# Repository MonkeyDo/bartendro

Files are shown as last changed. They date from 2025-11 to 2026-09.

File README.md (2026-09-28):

Original README 
============

Programs for the various systems of the Bartendro drink dispensing robot.

Created by [Pierre Michael](https://github.com/pmich) and [Robert Kaye](https://github.com/mayhem) ~ Copyright (c) Party Robotics 2010-2013

All of the source code in this repository is licensed under the GNU Public License 2.0.
The hardware schematic and layouts are licensed using the Creative Commons 
Attribution-ShareAlike 3.0 Unported license.

The source tree is laid out as follows:
  * firmware - source code (C) for the dispenser and router boards
  * scripts  - scripts to make running the bartendro software easier
  * ui       - web interface for the bot, written in python.

Fork README 
============

Requirements
==================================
Bartendro requires not just a RPI 4 but many other parts: a custom router board printed by Party Robotics, peristaltic pump dispensers, their individual mini-router boards, cabling, tubing, etc - the open schematics for these can be found in the [original repository in the /hardware folder.](https://github.com/partyrobotics/bartendro)

This project requires that you build your own Bartendro or procure one from a former Kickstart backer or client.

Without it the code will only run in Debug mode.

Code has been tested as working on
==================================
* [x] Raspberry Pi Os (Legacy, 32-bit) / Buster-armhf-lite (June 2019) / Note: only by using SD card image produced in 2021, Buster no longer supported by Raspbian
* [x] Raspberry Pi OS (Legacy, 32-bit) / Bullseye-armhf-lite (Aug 2021)
* [ ] Raspberry Pi OS (Legacy, 32-bit) / Bookworm-armhf-lite (June 2023)
* [ ] Raspberry Pi OS (Legacy, 32-bit) / trixie-armhf-lite (Aug 2025)
* [ ] Test any arm64-lite version of Raspberry Pi OS / `¯\_ (ツ)_/¯  will it run?`
| here is a link to the [official distro image archive for Raspiberry Pi OS](https://downloads.raspberrypi.com/raspios_lite_armhf/images/)

Releases
==================================
- 2021: .img to be flashed onto an SD card (Working on RPI 3 and 4, based on RaspiOS Bullseye 32-bit): [https://github.com/partyrobotics/bartendro/releases/tag/v-2021-05-21](https://github.com/partyrobotics/bartendro/releases/tag/v-2021-05-21)
- 2026: A snapshot of Bartendro as it was running in 2021 with python 2, before we merge in some improvements that were added at a later date. Removes "turbo mode" and "sobriety check" features that we are not going to use.: [https://github.com/MonkeyDo/bartendro/releases/tag/2021-python2](https://github.com/MonkeyDo/bartendro/releases/tag/2021-python2) 
- 2026: 

Getting started
==================================

- Read the [history of Bartendro](https://github.com/MonkeyDo/bartendro/blob/master/docs/history.md)
- Read our [Start Here guide](https://github.com/MonkeyDo/bartendro/blob/master/docs/2026-start-here.md)
- Read the [Install Guide](https://github.com/MonkeyDo/bartendro/blob/master/docs/2026-install-guide.md)
- Read the [User Guide](https://github.com/MonkeyDo/bartendro/blob/master/docs/2026-user-guide.md)
- Get hold of or build your own Bartendro (see Requirements above)
- Flash one of the Releases listed above onto a SD card with at least 4GB of memory and follow the [Install Guide](https://github.com/MonkeyDo/bartendro/blob/master/docs/2026-install-guide.md)
- Once you have the hardware setup and working follow the [User Guide](https://github.com/MonkeyDo/bartendro/blob/master/docs/2026-user-guide.md) to get your Bartendro calibrated and serving robo-cocktails!

Links to relevant code repositories
============

1. Archived bartendro code that can be found in [https://github.com/partyrobotics/bartendro](https://github.com/partyrobotics/bartendro) - what has not been forked from there:
  * hardware - schematics and layouts for the dispenser and router hardware boards
  * tsb - legacy code from our old skool drink bot prototype Tequila Sunrise Bot
2. An open sourced metal frame for holding 3 pumps and all the boards made by Wyolum: [https://github.com/wyolum/bartendro_frame](https://github.com/wyolum/bartendro_frame)
3. Rob's personal repos with additional configuration scripts (outdated): [https://github.com/mayhem/bartendro-config](https://github.com/mayhem/bartendro-config)
4. Rob's collection of BASH scripts to deploy bartendro: [https://github.com/mayhem/bartendro-deploy](https://github.com/mayhem/bartendro-deploy)
5. Ansible Cookbooks from 2013: [https://github.com/mayhem/bartendro-chef-cookbooks](https://github.com/mayhem/bartendro-chef-cookbooks)

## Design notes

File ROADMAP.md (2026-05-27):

# Roadmap

Some improvements we want to make to Bartendro to disentangle it from mayhem's Hippo Oasis and simplify the setup porocess, so it can be used by other people and find a good home.

0. Merge content of /mayhem/bartendro-config into /bartendro/scripts
   * [x] integrate readme.md from there into /docs
   * [x] review the scripts that affect networking - have the RPi setup an AP using available tools on RPI 4
   * [x] review the scripts that point to code running on other machines (this repo /scripts/start_bartendro.sh
   * [ ] create a new install.sh script for newer RaspiOS (Bookworm or above)
   * [ ] modify start_bartendro.sh to use only files within RPI and set to autostart on boot
1. Serve its own wifi access point
   * [ ] Bartendro should not need to connect to internet, so it should create its own AP (Wifi)
   * [ ] install.sh script should automate the selection of raspi-config options necessary for project:
     * [ ] Expand the filesystem (verify this process / requirement)
     * [ ] Set the hostname to bartendro (verify if this is still necessary)
     * [ ] Set the Wifi Country and setup Wifi to a valid network
     * [ ] Advanced: Disable console on serial port, enable serial port
     * [ ] Advanced: Enable I2C
2. Fix annoying bug where drinks will be poured directly from the drinks menu, without waiting for the confirmation screen
   * [x] Bug found to be called 'Turbo Mode' in the code, it exhibits itself when an admin changes settings in the backend and saves, when the backend refreshes it automatically ticks as active this 'turbo mode'
   * [x] Monkey has removed Turbo Mode and Sobriety Test, making a new Release in this repo
3. Better logging within admin UI
   * [ ] write verbose logs to file (rotate logs?)
   * [ ] in admin UI, show logs from file
   * [ ] optional: if admin wishes they can request output of RPI system and kernel logs (makes RPI run `tail -100 /var/log/syslog` or `tail -100 /var/log/kern.log` and displays it in the UI for easy debugging.
4. Create a Setup wizard - current setup is complicated and lots of manual work, requires figuring out combinations on paper and then importing the ingredients and cocktails to bartendro backend
   * [ ] wizard should allow you to easily select ingredients for each pump
   * [ ] then present a list of cocktails that can be served with the available ingredients
   * [ ] allow selecting (tickbox) the cocktails to put on the menu, and which section in the UI they go to
5. Stretch goal: cocktail explorer
   * [ ] need to find an appropriate free API, where you can search by multiple ingredients
   * [ ] on bartendro admin, input your available liquids and fetch a list of cocktails that use them
   * [ ] then import cocktail recipes right into the bartendro database
6. Strech goal: Create new .img release after code has been tested as working on Raspberry Pi 4 (Bullseye, 32 bit)
   * [ ] include: raspi-config already run (setting Wifi country to ES/Spain)
   * [ ] include: all files from the repo
   * [ ] include: information in release page regrading username & passwd + wifi SSID & password of AP
7. Strech goal: Test if Bartendro works for other versions of Raspberry Pi OS
   * [ ] Raspberry Pi OS (Legacy, 32-bit) / Bookworm-armhf-lite (June 2023)
   * [ ] Raspberry Pi OS (Legacy, 32-bit) / trixie-armhf-lite (Aug 2025)
   * [ ] Any 64-bit version of Raspberry Pi OS / `¯\_ (ツ)_/¯  will it run?`
   * [ ] Test if it runs on a RPI 5 (why not?)
8. Investigate user_button.py
    * [x] ref: https://github.com/MonkeyDo/bartendro/commits/master/scripts/user_button.py
    * [x] We discovered it was the code for a custom button that Rob had installed on his personal bot, which allowed for the `bartendro_server.py` to be restarted manually by pressing a button. At somepoint in time Rob replaced this with an LED that indicates whether the liquid levels were low within the backend of the program.
    * [ ] Consider deletion of this code for this repo since it relates to an 'after-market' modification

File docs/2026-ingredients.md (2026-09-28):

# Recommendations of ingredients for cocktails that work well with Bartendro

## Verbotten Flüssigkeit / DO NOT USE
- carbonated drinks such as soda water, tonic water, coca-cola, soft drinks - bubbles do not work well with the pumps and some of these liquids are corrosive to the delicate parts.
- Cream-based drinks such as  Kahula, Baileys, Coconut cream - they leaves sticky residue that rots the tubing
- Non-filtered aromatic water / infusions with sediments - particulates can get trapped in tubes or pumps
- Juices with pulp - whether hand-pressed or commercially bought - do strain out any pulp and fiber from juices

## Strong booze
- Whiskey
- Bourbon
- Light Rum
- Dark Rum
- Gin
- Vodka
- Tequila
- Mescal
- Triple Sec
- Absinthe

## other booze
- Campari
- Martini
- Amaretto
- Amaro
- Cognac
- Armaniac
- Drambuie
- Cointreu

## Mixers
- Grenadine
- Simple Syrup
- Cordial water / natural syrups
- Aperol
- Mint-infused water
- Kefir Lime infused water

## Juices 
- Orange
- Pineapple
- Cranberry
- Apple
- Lemon (hand-squeezed)
- Lime (hand-squeezed / caution: energy intensive)

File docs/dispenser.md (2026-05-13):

Documentation for Bartendro Dispenser

Functional overview
===================

The Bartendro Dispenser can dispense liquid with milliliter accuracy and can be 
used in a stand alone system or in combination with a router and other pumps to create a more
complex liquid dispensing system.

The functions this dispenser can perform are:

- Run the pump for a number of milliseconds.
- Run the pump for a number of rotations (or quarters of rotations)
- Set the built-in LED colors and run LED animations
- Estimate the amount of liquid left in a bottle
- Sense when the pump is seizing and shut off power to the motor
- Track use of the pump using number of rotations.

Hardware overview
=================

Bartendro uses a star network topology using RS-232 (serial) communications.
A Bartendro drink bot usually contains a Raspberry Pi (RPI), a router board for communicating 
with dispensers and up to 15 dispensers. Using the router, the RPI can select one dispenser at
a time and communicate with it or communicate in broadcast mode to all of the dispensers at the 
same time. 

While these docs focus on discussing the dispensers, you need to be aware of what the router
does in order to fully understand all of the communication nuances of our dispensers. Because
of the router, each dispenser is programmed with a dispenser id that uniquely identifies a 
dispenser in the system. This id needs to be received from the dispenser at the start of the 
communication with the dispenser.

Each dispenser also contains 4 tri-color LEDs connected to a WS2801 LED driver chip that handles
the PWM functions to set the LEDs to a given color. All LEDs in one dispenser are connected
to one WS2801 chip and cannot be independently addressed. Given that the RPI cannot communicate
with all of the dispensers at exactly the same time, we've included a SYNC signal from the router
to each of the dispensers. This SYNC signal is used to synchronize LED animation patterns
stored in the dispensers. The dispenser changes the color of the LEDs based on the stored
pattern periodically based on the SYNC signal.

Accuracy considerations
=======================

Pumping speed and accuracy are sometimes in conflict. 

For instance, if you are dispensing 10ml via the dispense ticks method at full speed (speed 255), 
you are likely to get about 2ml more output that you asked for. The reason for this is that the
motor requires more time to spin down from full speed once the desired number of ticks is reached.

Rather than forcing one method on all of our users, we ask you to consider the proper handling
of this quirk of our dispensers. We suggest the following methods:

1. The ostrich solution: If you care about dispensing larger volumes and being off by 2ml is not a 
problem, then don't worry about it.

2. The sloppy method: Dispense 2ml less at full speed than you actually plan to dispense. This should
work out ok, but its... sloppy.

3. The slow, but sure method: Reduce the speed to half speed. The "overpour" will be negligible and your
output will be correct, but slower.

4. The corporate american way: Dispense your desired amount at full speed, less 10ml. For the last 10ml,
dispense at half speed. This is how the oil companies ensure they don't give you one cent of gas too much. :)

IMPORTANT NOTE: The above instructions assume that you provide the pump motor 24V. If you provide
less voltage your results may differ and you should test the results accordingly.

Communicating with a dispenser
==============================

After power up, the LEDs in the pumps will turn blue, waiting for communication. If a pump 
starts up and has a solid red color, its is missing a dispenser id that needs to be 
programmed into eeprom. See eeprom section for more information on this.

To initiate communication, the user should send the question mark character '?' to the pump. 
The dispenser will respond with a one byte response that is its dispenser id. The dispenser 
will continue to respond to '?' characters until it receives a 0xFF character, indicating that 
the dispenser user has captured the dispenser id and communication can start. The user should 
save the dispenser id as it will be required to address the dispense in subsequent communication.

Once the dispenser is ready for communication it will display its "idle" LED pattern which is a 
rainbow color changing pattern. At this point the dispenser is ready to receive a packet
of data. Now the user may send a packet of data to the dispenser. The dispenser will respond
with either a single byte ACK code, or a complete packet, depending on the type of
packet that was sent.

Each packet contains a destination field, which is the dispenser id that was captured
in the beginning of communication with the dispenser. While this may seem silly in a single
dispenser setup, its important when more than one dispenser is used in conjunction with 
a router. All packets sent from the router are sent over one serial TX line to ALL dispensers
connected to the router. All dispensers receive the packets and if the packet is not
marked as a broadcast packet or marked with its dispenser id, the dispenser will ignore
the packet. If a dispenser receives a packet that is a broadcast packet it must take the
appropriate action and NOT SEND a response. Broadcast packets should NEVER be replied to. 
If a dispenser receives a packet with its dispenser id, it must take action and then 
send a response to the user. Depending on the packet type, a response can either be 
a single character ACK code, or a complete packet in response.

For more information on how packets are structured, packet types and if they require
a response, see the detailed packet sections below.

Packet structure
================

Packets are comprised of two sections:

 * Header: 2 characters, always 0xFF 0xFF
 * Packet body, which is 7 bit data escaped, 10 bytes long

This packet body must be encoded into 7 bit data, so that the MSB of any data in the packet will
never be set. This allows the dispenser to clearly identify a packet header, which is the 
only data to ever have the MSB set in an entire packet. For details on how to encode data
to 7 bits, please see firmware/common/pack7.c[|h]. 

The data in the packet, when unpacked is 8 bytes long:

 * unsigned byte: destination dispenser id -- the dispenser id discovered during the 
   communication setup or BROADCAST_DEST.
 * unsigned byte: packet type -- one of the packet types described below
 * 4 bytes of payload data -- Either a 32 bit value, 2 16 bit values or 4 8 bit values.
 * unsigned 16 bit word: 16 bit CRC value calculated for the destination, type and payload
   value. For the details of this algorithm, see the function crc16_update() in
   ui/bartendro/router/driver.py

Sending packets
===============

Packets should be sent to the dispensers with a baud rate of 9600, no party and 1 stop bit.
After sending 10 bytes, the user should wait until the dispenser sends a response. Most packet 
types will get a single byte ACK code response and some will get a complete packet as a response.
Packets that receive a full response are:

 * PACKET_IS_DISPENSING 
 * PACKET_LIQUID_LEVEL
 * PACKET_UPDATE_LIQUID_LEVEL
 * PACKET_SAVED_TICK_COUNT
 * PACKET_GET_LIQUID_THRESHOLDS

All other packet types will receive a simple ACK code, consisting of one of the following:

 * 0 - PACKET_ACK_OK       -- packet received OK and acted upon
 * 1 - PACKET_ACK_CRC_FAIL -- packet data was corrupt and was not executed
 * 3 - PACKET_ACK_INVALID  -- the packed was improperly packed to 7 bits and did not yield 8
                              bytes of packet data.
 * 4 - PACKET_ACK_INVALID_HEADER -- an incomplete header (only one 0xFF character) was received
 * 5 - PACKET_ACK_HEADER_IN_PACKET -- An header character (0xFF) was received in a packet, 
                                      which is invalid.

For any packet that requires a complete response (any packet that returns data and not just an 
ACK) the dispenser will respond by sending a complete packet in response. Once this packet has
been received by the user, a single character ACK, as described above, must be sent to the
dispenser.

Packet types
============

The following packets can be set to/from the dispenser:

* PACKET_PING -- A diagnostic to see if the dispenser is alive. No action is taken. Contains
  no data payload.
* PACKET_SET_MOTOR_SPEED -- Turn the motor on at a given speed. The max speed is 255, which 
  should be suitable for most applications. If you'd like the dispenser to turn more slowly, 
  you can give it a slower speed. Slower speeds can be useful for dispensing smaller quantities
  of liquid or where more fine grained control is required. We recommend to not set the speed
  below 64, since at that speed the motor can barely overcome the friction to turn the pump.
  To turn the pump off completely, set the speed to 0. Once this command is initiated, the 
  dispenser will immediately return an ACK and it will not wait for the dispense function to 
  complete. Data payload is motor speed as a 8 bit unsigned int in the first byte and wether
  or not to enable over current sense in the second 8 bit unsigned int.
* PACKET_TICK_SPEED_DISPENSE -- Dispense for a certain number of ticks at a given speed. Dispenser
  rotation is measured in "ticks" which are generated by magnets moving over hall sensors in the 
  dispenser. There are 4 hall sensors, so it takes 4 ticks for the pump to make one full turn. 
  This function is the most accurate way to dispense a liquid. We've determined that the pump 
  dispenses 1 milliliter in 2.78 ticks. Once this command is initiated, the dispenser will 
  immediately return an ACK and it will not wait for the dispense function to complete. The number
  of ticks to dispense is an unsigned 16 bit payload and the speed to dispense (max speed is
  255!) is the second unsigned 16 bit payload.
* PACKET_TIME_DISPENSE -- Dispense for a certain number of milliseconds. The 32 bit payload
  determines the number of milliseconds the pump should run for. Tick counting is completely
  ignored with this command. Payload is a 32 bit unsigned integer.
* PACKET_LED_OFF -- Turn off the LEDs in the dispenser. No payload.
* PACKET_LED_IDLE -- Display the "idle" pattern in the dispenser. No payload.
* PACKET_LED_DISPENSE -- Display the "dispense" pattern on the LEDs. No payload.
* PACKET_LED_DRINK_DONE -- Display the "drink done" pattern. No payload.
* PACKET_IS_DISPENSING -- This function asks the dispenser if it is still dispensing. Since
  the dispense commands return immediately and don't wait for the dispense to complete,
  the user needs a method to determine if a dispense is complete. This call enables that.
  This packet requires a complete packet response. There is no data payload for the
  request sent from the user, but the dispenser responds with a boolean response (is dispensing)
  in the first byte of the payload and if the over current sensor has been triggered in the 
  second byte of the payload.
* PACKET_LIQUID_LEVEL -- If a dispenser is equipped with a liquid level sensor, this call
  will return the liquid level saved in the dispenser's ram. Liquid levels are not read on 
  the fly -- instead a stored value will be returned to the user. To update the stored value 
  with the current value use the PACKET_UPDATE_LIQUID_LEVEL command. The liquid level in the 
  bottle (or whatever vessel might be used) is expressed as 10 bit value (0 - 1024). Liquid
  level sensors are sensitive devices that require a minor amount of calibration. Each liquid
  level sensor may have a slightly different idea of what "empty" means. For more information
  on how to interpret these values, please see the section "liquid level sensors". If the
  dispenser is not equipped with a liquid level sensor, the values returned by this command
  are undefined. This packet requires a full packet response. Packets sent to the dispenser
  contain no payload. Packets sent from the dispenser contain a 10 bit value in the
  first 16 bit value in the payload.
* PACKET_UPDATE_LIQUID_LEVEL -- Use this command to force the dispenser to update the 
  current liquid level. We recommend that you let at least 5ms pass between updating the 
  liquid levels with this command and reading them with PACKET_LIQUID_LEVEL. No payload.
* PACKET_ID_CONFLICT -- If two dispensers connected to one router have the same dispenser id,
  it creates an ID conflict. This command turns the pump LEDs red and cause the pump to
  do nothing until it is reset. No payload.
* PACKET_LED_CLEAN -- Set the LEDs to the "clean" pattern. No payload.
* PACKET_SET_CS_THRESHOLD -- This command sets the threshold value at which the motor is 
  considered to be seized and should be turned off. This can happen when hoses get old or
  are otherwise obstructed. To prevent the motor from burning out, the current sensor
  determines when a motor is working too hard and shuts off the pump. The default value
  programmed into the dispensers should suffice for most uses. For more information see
  the section "over current protection". The current sense limit should be given in 
  the first 16 bit value of the payload.
* PACKET_SAVED_TICK_COUNT -- This command retrieves the tick count saved in the dispenser's
  eeprom memory. It tells you how many ticks (turns if you divide ticks by 4) the dispenser
  has turned since the tick counter was reset. This feature is to measure hose life and to give
  the user of the dispenser an idea when the hoses inside the pump need to be replaced. This
  packet requires a full packet response. Packets sent to the dispenser contain no payload. 
  Packets sent from the dispenser contain a 10 bit value in the first 16 bit value in the payload.
* PACKET_RESET_SAVED_TICK_COUNT -- This command resets the stored tick count in the dispenser's
  eeprom memory. This value should only be reset when the hoses inside the dispenser have been
  changed. No payload.
* PACKET_GET_LIQUID_THRESHOLDS -- This command is used to query the liquid out thresholds stored
  in the dispenser's eeprom memory. This packet requires a full response and the response packet
  will contain two 16 bit values: "low" threshold and "out" threshold. For more information
  on liquid level thresholds, please see the section "liquid level sensors". The first
  16 bit value of the payload is the "low" threshold and the second 16 bit value is the "out"
  threshold.
* PACKET_SET_LIQUID_THRESHOLDS -- This command sets the liquid level thresholds. Two 16 bit 
  values for "low" threshold and "out" should be contained in the packet. For more information
  on liquid level thresholds, please see the section "liquid level sensors".
* PACKET_FLUSH_SAVED_TICK_COUNT -- This command should be sent to the dispenser before shutting 
  down the dispenser. The dispenser keeps track of the current tick count in RAM and only 
  flushes it to eeprom periodically to prevent the eeprom memory from wearing out. To ensure 
  that the accurate tick counts are stored in the pump, make sure to call this command before 
  shutting down the dispenser. No payload.

Deprecated commands:

* PACKET_TICK_DISPENSE -- Dispense for a certain number of ticks. Pump rotation is measured in
  "ticks" which are generated by magnets moving over hall sensors in the dispenser. There
  are 4 hall sensors, so it takes 4 ticks for the pump to make one full turn. This function
  is the most accurate way to dispense a liquid. We've determined that the pump dispenses
  1 milliliter in 2.78 ticks. Once this command is initiated, the dispenser will immediately
  return an ACK and it will not wait for the dispense function to complete. The number
  of ticks to dispense is an unsigned 32 bit payload, but only the 16 bits of data will be used.
  This command is deprecated in favor of the PACKET_TICK_SPEED_DISPENSE that allows the user
  to specify the speed with which to dispense.

EEPROM
======

The EEPROM of the Atmel atmega168a micro-controller contains the following pieces of
data:

   offset     data type         data
   0          8 bit unsigned    Dispenser id
   1          32 bit unsigned   Run count in ticks
   5          16 bit unsigned   Liquid "low" threshold
   7          16 bit unsigned   Liquid "out" threshold

To get a working dispenser, you will need at least to minimally write a dispenser id 
into the first byte into eeprom RAM. This can be any value but 0 or 255. 

Dispensers shipped from PartyRobotics have this dispenser id set. You can set another
dispenser id (chosen randomly) by running the script in /firmware/dispenser/pump.sh

Resetting the dispenser
=======================

To reset the dispenser, the user needs to hold the RESET line high for at least 1ms. This will
do a software reset that causes the dispenser to stop what it is currently doing and
enter the address discovery mode as it normally would on startup.

Liquid level sensors
====================

The liquid level sensors that are available for our dispensers allow the dispenser to
estimate the amount of liquid left in a bottle. The "liquid level" sensors are really
differential pressure sensors that measure the difference between ambient air pressure
and a liquid level hose that rests in the bottle. The liquid in the bottle exerts a tiny
amount of pressure on the hose and there for on the sensor. As the liquid level in the
bottle drops, the pressure approaches the ambient pressure. Once the pressure exerted
on the hose is equal to ambient pressure, the bottle is empty. 

Care should be given to never empty a bottle fully, because if the intake hose sucks
air while dispensing, an inaccurate dispense occurs. To avoid this, the liquid "out"
threshold should be set conservatively so that the dispenser will consider a bottle to
be empty before it is actually empty.

These sensors are sensitive devices that require some calibration. Even at ambient 
air pressure, not all sensors are going to return the value absolute value. Depending on
how you plan to use the pressure sensors we encourage you to read the pressure sensor
readings at different liquid levels to get acquainted with how the sensor works.

Over current protection
=======================

Each dispenser also comes equipped with an "over current sense" circuit. This
circuit estimates the amount of current that the motor in the dispenser consumes. If for
some reason the motor binds up and consumes large amounts of current, the dispenser
stops the motor and flashes the red LEDs quickly. At this point the dispenser refuses
to engage the motor again until the dispense has been reset. 

Empirical testing has shown that the default value of 465 works well for the motor
running at full speed. You can provide different current sense threshold values
using the PACKET_SET_CS_THRESHOLD command.

Color error codes
=================

The dispenser's only real form of end-user feedback is the color of the dispenser. The
following colors/animations are programmed into the stock dispenser:

* Solid RED at startup: id conflict
* Solid BLUE at startup: ready for communication, waiting for user to initiate 
  communication.
* Solid GREEN: A 0xFF character has been received after communication startup. The
  dispenser is now waiting for the first command from the user.
* Rainbow color animation: idle mode. The dispenser is waiting for commands from the user.
* Red <-> blue color animation: Dispenser is dispensing liquids.
* Pulsing green color animation: Dispsener is done dispensing liquids.
* Pulsing purple color animation: Dispenser is currently being cleaned. This mode really
  only has significance in the context of a larger setup where the RPI can execute
  a clean cycle using multiple dispensers.

Dispenser factsheet
===================

__Archive of https://core-electronics.com.au/bartendro-dispenser-peristaltic-pump-and-controller.html__

Do you need to precisely dispense amounts of liquid for your preferred beverage? If so this could be the pump for you. This is the Bartendro Dispenser from Party Robotics, an ingeniously designed peristaltic pump and controller that can be used to dispense liquids with milliliter accuracy and can be used in a stand alone system or with a router and other pumps for a more complex liquid dispensing system. This peristaltic pump works through positive displacement, two rollers are attached to a single motor that spins around a Norprene® tube pinching it closed to force your beverage liquid to be pumped through. With this method you won’t need to worry about your liquid flowing through any moving parts, it will bypass the need for flow meters, and you will be able to meter the amounts of beverage liquid independent of viscosity and density.

Unlike most peristaltic pumps, the Bartendro Dispenser comes equipped with a controller board (driven by the reliable ATMega168), RJ45 and liquid level sensor connectors, and even a few WS2801 RGB LEDs just to make your drink provider all the more pretty.

The only things that the Bartendro really need to get going is a bit of motor power (minumum of 12V, max 24V), logic power, and serial communication all of which are supplied over the RJ45 jack found on the back of the board. Basically all you need to do is form a serial communication with this board via Arduino, Raspberry Pi, pcDuino, or any other development board of those natures and you will be good to start pouring!

Features:

* Max Flow rate: 700mL/ min
* Minimum Motor Voltage (Vin): 12V
* Motor Voltage (Vin): 24V
* Minimum Dispense Volume: 0.5mL if using PWM
* Repeatability: 1mL or better
* Current Consumption at 24V: up to 500mA while dispensing
* Max Vertical Tubing Length: about 10ft
* Max Length of Serial Connection: 10ft
* Tube Life: 500 Hours
* Food Safe

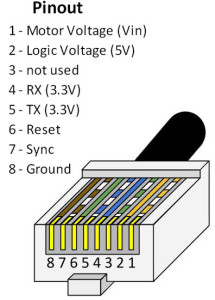
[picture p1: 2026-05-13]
docs/dispenser-pinout-diagram.jpg

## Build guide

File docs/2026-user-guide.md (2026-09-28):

## User Guide: how to calibrate Bartendro and serve your first robo-cocktail!

### BEFORE YOU BEGIN

* you have read the 2026-install-guide.md documentation
* you have a working Bartendro and have managed to connect to the Wi-Fi network it creates
* you have a tablet / phone / laptop that can be used to operate Bartendro
* you have several large capacity buckets and jars for your favorite liquids
* you have purchased all your favorite liquids (no carbonated drinks or pulpy juices!)
* you have a bunch of thirsty friends and cups they can use
* you have read the rest of this documentation till the end
* one towel per traveler

## CLEANING
* For sanitary reasons, prior to operating Bartendro you must clean the tubing with various rounds of soapy and clean water before loading the liquids you wish to serve as delicious robo-cocktails.
* Place Bartendro on a table/stable surface, one you do not mind getting some water and liquids on it.
* Twist to remove the pump from the dispenser, access it from behind the clear casing where the inner tubing of the pump and plastic connectors to the intake and outflow tubing is also accessible. 
* Take the rotor component for the pump and slide in place within the clear casing, ensure the 'cross' side of the pump is facing the motor end it needs to connect to on the mini-router board.
* Do this gently, it is useful to pry the tube out of the clear casing and then place the pump inside before sliding it back into the clear casing as one piece. Once all pumps are assembled you can proceed with cleaning.
* Fill one large jar/container/bucket with at least 1 litre of clean water
* Get a second large jar/container/bucket located near the output of the dispensers to collect the outflow water
* Connect Bartendro to power and turn the robot on, wait 2-3 minutes for the Pi to boot and network to appear
* Connect to the Wi-Fi network and navigate to `http://bartendro.local`
* Once the app is loaded, click/tap in the top-right hand corner (the bartendro logo)
* This will bring you to the admin login screen, input the username and password that you created during the installation or go to `http://bartendro.local/admin/lost-passwd` if you forgot it.
* Once you are in the admin backend, use the top navigation tabs select 'Dispensers'
* Within the Dispensers menu, scroll to the bottom to find the green 'clean' button.
* Ensure all the intake tubes of the dispensers are immersed into the water and that there is a container ready to receive the outflow - Bartendro will output a lot of volume in this process
* Click the button and wait for the clean cycle to finish - dump the water that passed through the machine, refill the container with clean water and a very small amount of dish-soap (emphasis on small)
* Run the clean cycle two more times with the lightly soapy water, then dump all the contents of the containers used and refill the intake one with clean water
* Run one last cycle with only clean water, to remove any soapy residue within the tubes.
* Empty the water containers and wipe the table/surface (it will get wet I promise you, have a towel at hand)

## SETUP 

* Place the bottles/jars with liquids where the clear tubing of each dispenser can reach the bottom of the bottle/jar
* Take a note of the maximum capacity of each container, the estimated current volume of liquids inside, and the pump number it is connected to
* Within the same Dispensers Menu you will need to select the liquid name (drop-down menu) and then add in the capacity and estimated current volume for each liquid you are serving.
* Once you go through all the dispenser pumps and have all the intake tubes within the bottles/jars you can now make a menu and do some testing
* To generate a new menu (which is what the humans will see on homepage of webapp), go to the 'Menu' tab within admin
* Select items from the extensive pre-installed selection of drinks or generate your own
* Be mindful that bartendro will only serve cocktails it has liquids for - if your dispensers have 'light rum' and the cocktail recipe requires 'dark rum' the robot will think it is out of rum.
* ...
* TBC
* ...
* 
* Place a tablet/laptop/phone where the user can interact with the Bartendro menu near or ontop of the robot
* Tip: set the homepage as `http://bartendro.local`, remove other saved Wifi networks on the device, and make the web-browser to be full-screen for the best experience as an operator

## OPERATION 

* ...
* TBC
* ...
* 
* 
* 
* 
* 

## CLEAN-UP 

* ...
* For maintenance reasons it is vital to the robot that you clean the tubing with various rounds of soapy and clean water after having served many delicious robo-cocktails.
* Take out all the tubes from the liquids used during operation, place the intake end into a large jar/container/bucket filled with at least 1 litre of clean water.
* Get a second large jar/container/bucket located near the output of the dispensers to collect the outflow water
* Using the app go to the admin dashboard, use the top navigation tabs select 'Dispensers'
* Within the Dispensers menu, scroll to the bottom to find the green 'clean' button.
* Ensure all the intake tubes of the dispensers are immersed into the water and that there is a container ready to receive the outflow - Bartendro will output a lot of volume in this process
* Click the button and wait for the clean cycle to finish - dump the water that passed through the machine, refill the container with clean water and a very small amount of dish-soap (emphasis on small)
* Run the clean cycle two more times with the lightly soapy water, then dump all the contents of the containers used and refill the intake one with clean water
* Run one last cycle with only clean water, to remove any soapy residue within the tubes.
* Empty the water containers and wipe the table/surface (it will get wet I promise you, have a towel at hand)
* Similarly to the cleaning of tubes, to ensure the longevity of the robot you must remove in place the peristaltic pumps from within the dispensers so that there is not a constant pressure on the internal tubing of the pump.
* Twist to remove the pump from the dispenser, access it from behind the clear casing.
* Gently pry the tube out of the clear casing by pulling on the plastic pump rotor, place the tube back inside casing once the pump is removed. Place the casing back on dispenser and the pump part within a sealed jar or ziplock bag.
* Go home, eat something, drink lots of water and take two aspirins in the morning whilst wondering 'where are my keys?'

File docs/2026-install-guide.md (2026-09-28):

## Guide: How to install Bartendro on a new machine

### BEFORE YOU BEGIN

Bartendro requires not just a RPI 4 but many other parts: 
* a custom router board printed by Party Robotics (DIY manufacturing)
* a number of dispensers
* same number of minirouters for each dispenser
* cabling, tubing, etc

the open schematics of these can be found in [the original repo in the /hardware folder.](https://github.com/partyrobotics/bartendro/tree/master/hardware)

This project requires that you build your own Bartendro or procure one from a former kickstart backer or client.

In this revival of the code, we will seek to test it on other platforms and OS versions, but at this moment Bartendro only works on a RPI 4 running 32-bit RaspiOS based on Buster - please see ROADMAP.md for updates on our testing.

There are currently **two ways** in which a new user can setup a Bartendro bot using this repository: **the lazy way** (flashing an image onto an SD card) and **the nerd way** (SSH or connect a monitor to the RPI and setup Bartendro using the command line). 

We have only tested the Lazy Way and the image linked below is the updated 2026 version, if you wish to flash the original SD card image please download the file in the [2021-05-21 release from Party Robotics.](https://github.com/partyrobotics/bartendro/releases/tag/v-2021-05-21)

### THE LAZY WAY

* get a Raspberry Pi model 4 and an SD card (4GB at least)
* download the 2026 version of the .img file from the [latest releases](https://github.com/MonkeyDo/bartendro/releases) - this image has been bundled with all the necessary dependencies and requirements for the software.
* flash the image onto the SD card using software such as RPI Imager, Balena Etcher, Rufus or other.
* insert SD card into RPI slot 
* connect the RPI to the the Bartendro control board via the GPIO pins
* connect pumps to the control board using the Ethernet cables
* power up the RPI using the correct power supply (the control board gets power from the RPI)
* if all goes well the LEDs on the pumps should turn on and a new Wifi network called `bartendro` should appear 
* can connect to `bartendro` wifi / the password is `boozemeup`
* After connecting a captive-portal should pop-up on your device, if not use a web-browser and navigate to 10.0.0.10 or bartendro.local
* Note: If there is no wifi network something went wrong with setup, verify the SD card is well seated in the slot on RPI and try again.
* Note: In this release the Wifi Country is set to ES (Spain) within the RPI settings, if you are in a different country you should run `sudo raspi-config` on the RPI to be able to change it to your current region (this affects which bands the wifi uses)
* Fill up your containers and test the pumps are working 
* See 2026-user-guide.md for how to use the UI and calibrate Bartendro before serving your first robo-cocktail!

### THE NERD WAY

1. Flash
* Download and write the RaspberryPi OS Lite to an SD Card - Bartendro has only been tested as working on the Raspberry Pi OS (Legacy, 32-bit) / Buster-armhf-lite (March 2021) - [Direct download](https://downloads.raspberrypi.org/raspios_lite_armhf/images/raspios_lite_armhf-2021-03-25/2021-03-04-raspios-buster-armhf-lite.zip) 

2. RPI related configuration
* Insert flashed SD card into RPI slot and boot the device
* SSH into the RPI **or** connect a monitor and keyboard to the RPI
* Boot the RPi and then log in as user 'pi' with password 'raspberry'
* From the command line run `sudo raspi-config`
  * Localisation Options: Set the Wifi Country and setup Wifi to a valid network (option L4)
  * System Options: Connect to your wifi here if you are not using a Ethernet cable (option S1)
  * Interface Options: Enable SSH (Option I2)
  * (Optional) Interface Options: Disable console on serial port (first choice: NO), but do enable serial port (second choice: YES) (Option I6)
  * (Optional) Interface Options: Enable I2C (Option I5)
  * (Optional) Advanced Options: Expand the filesystem (option A1)
  * navigate to 'Finish' & select YES when asked if raspberry pi should reboot (IMPORTANT)

3. Running the online setup script
* Once the RPI reboots fully use another device to `ssh pi@bartendro.local` (or use monitor and keyboard attached to the RPI)
* Log in again (pi/raspberry) and run:

```
curl -fsSL https://raw.githubusercontent.com/MonkeyDo/bartendro/main/scripts/installation/setup_raspbian_image.sh | sudo bash
```

* The setup wizard will ask for the Bartendro user, password, Wi-Fi access point SSID/password, and network settings. Press Enter to accept each default.
* This step must run while the Raspberry Pi still has internet access. It installs system packages, creates the `bartendro` user, clones this repository, installs Python dependencies, and stages the offline access point scripts.
* If setup is interrupted, rerun the same command or resume from a named step. For example:

```
curl -fsSL https://raw.githubusercontent.com/MonkeyDo/bartendro/main/scripts/installation/setup_raspbian_image.sh | sudo bash -s -- --start-at python
```

4. Switch to Bartendro access point mode
* After the online setup completes, run:

```
sudo setup-bartendro-local-ap
```

* Verify the finished setup with:

```
sudo check-bartendro-setup
```
(Scripts are in the folder `/usr/local/sbin/`)

* Reboot for good luck. Now the Pi should create a Wi-Fi network using the SSID/password selected in the wizard.
* Once done rebooting, connect to bartendro's Wi-Fi with the user/password selected in the wizard. (defaults: `bartendro`/`bartendro`) You can use a phone, laptop or tablet for this. Your device may give an error that the network does not have internet connectivity, this is by design, you can safely ignore this.
* Once connected use the web-browser to connect to the app at `http://bartendro.local/` - this should load up the bartendro main page
* Tap/click on the top bartendro logo in the top right of the page to access the admin settings using the username and password provided during the install script (defaults: `bartendro`/`boozemeup`)

5. Troubleshooting 
* As an additional step you can also remove the 'pi' user from sysytem: `sudo deluser --force --remove-home --remove-all-files pi` - note: if you do this step you can now you can no longer log in as `pi`.
* Forgot the password or want to set a new one?  navigate to the `http://bartendro.local/admin/lost-passwd` webpage when connected to Bartendro Wi-Fi
* Having problems accessing `bartendro.local`? - double check you are connected to the WiFi network created by the Pi, it can be helpful to remove 'auto-connect' from your configuration for other nearby wifi networks to avoid it connecting to those.
* Getting TLS/SSL certificate or secure connection errors? - this is be design, bartendro does not have a signed SSL certificate, if you can not access the app then ensure that the URL in your browser starts with `http://` and not `https://`

"In theory that should be it. Your SD card should be ready to rock." - Mayhem

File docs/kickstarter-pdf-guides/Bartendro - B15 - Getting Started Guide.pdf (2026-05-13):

# Getting Started Guide

BartendroTM | B15

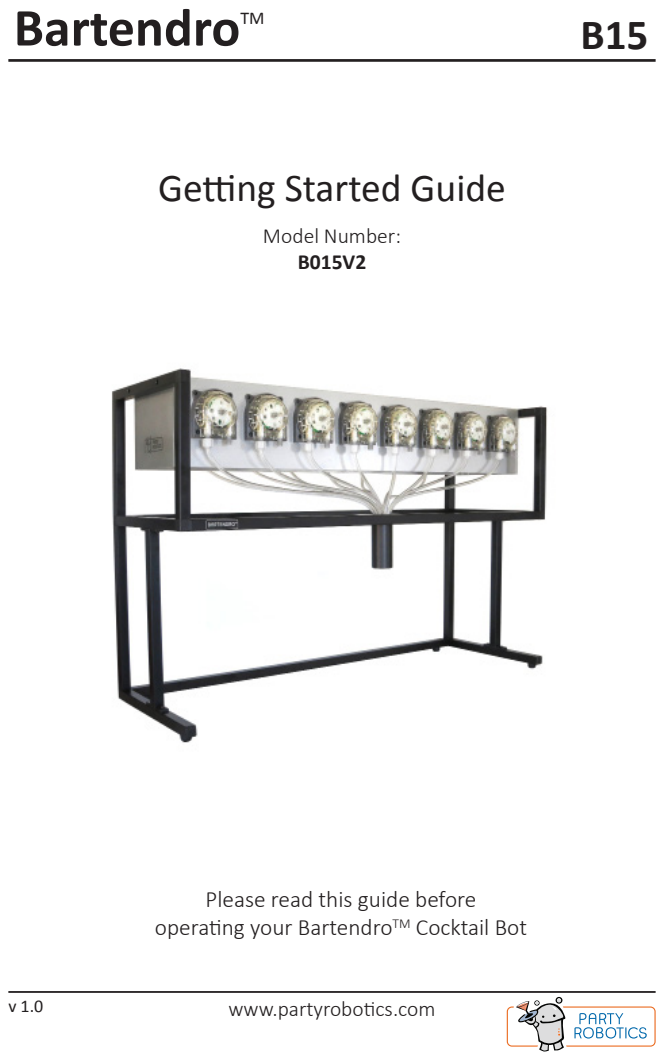
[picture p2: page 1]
Model Number: B015V2

Please read this guide before
operating your BartendroTM Cocktail Bot

www.partyrobotics.com

Important Precautions

- Do not use Bartendro or its components for medical or life-critical applications.
- Avoid touching electronics when possible. The electronics in Bartendro may be damaged by static electricity, the sort your hands can pick up from shuffling your feet across the carpet. If you need to touch them, make sure to first discharge yourself by touching something metal connected to ground like a faucet or metal appliance.
- Plugging and unplugging dispensers while the system is powered may cause permanent damage to your Bartendro.
- Powering the Router board without the Raspberry Pi and dispensers plugged in may cause permanent damage.
- Plug networking devices into the port available on the back of your Bartendro. Plugging them into any other RJ45 connector on the Router Board will cause damage.
- It is not recommended to keep clear tubing immersed in liquid for extended periods of time. Doing so may cause discoloration, or cause mold to form.
- If storing Bartendro for more than several weeks without use, we recommend removing the beige tubing from the dispensers to extend tube life.
- Please drink and use responsibly.

You will need
Phillips screwdriver
Device with web browser (phone, tablet, laptop, etc.) Wired Networking Router (for software updates) Computer (for software updates)

Congratulations!

You are one of the first owners of the latest in cocktail dispensing technology. BartendroTM Cocktail Bots and Dispensers pour a variety of liquids precisely, and you can control them from phones or tablets. Whether you set up your bot to host a party, or use it for mixing flavored syrups into sno-cones, it will be sure to liven things up. What applications will you come up with? Please share your projects at: http://partyrobotics.com/forums/forum/sharing/

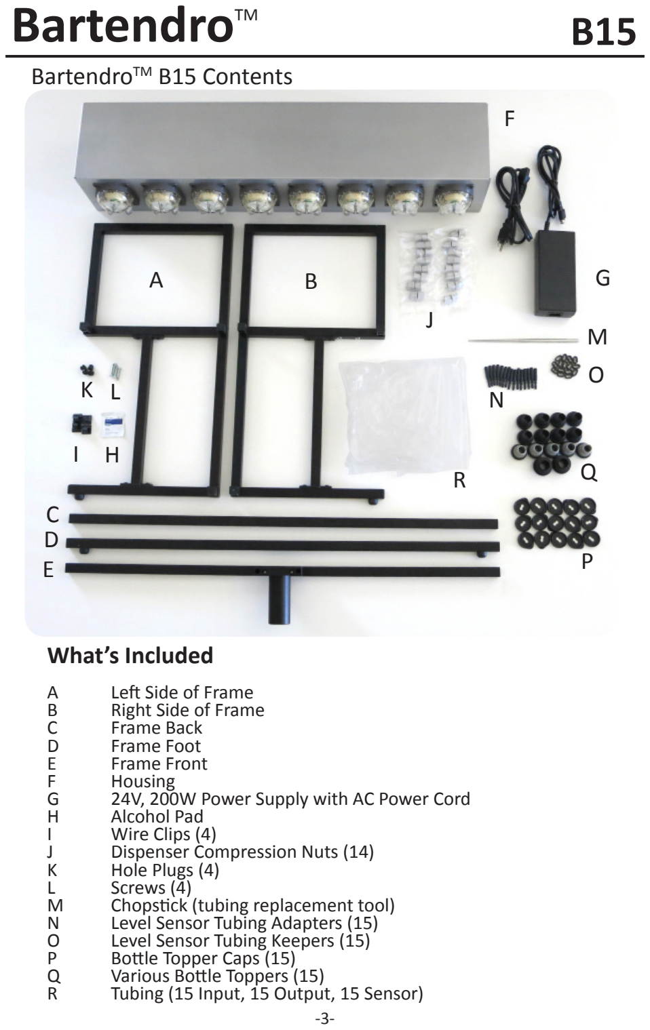
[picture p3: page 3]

BartendroTM B15 Contents

What’s Included
A | Left Side of Frame
B | Right Side of Frame
C | Frame Back
D | Frame Foot
E | Frame Front
F | Housing
G | 24V, 200W Power Supply with AC Power Cord
H | Alcohol Pad
I | Wire Clips (4)
J | Dispenser Compression Nuts (14)
K | Hole Plugs (4)
L | Screws (4)
M | Chopstick (tubing replacement tool)
N | Level Sensor Tubing Adapters (15)
O | Level Sensor Tubing Keepers (15)
P | Bottle Topper Caps (15)
Q | Various Bottle Toppers (15)
R | Tubing (15 Input, 15 Output, 15 Sensor)
A | B

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
R | Q

## Step 1

## Assembly Instructions

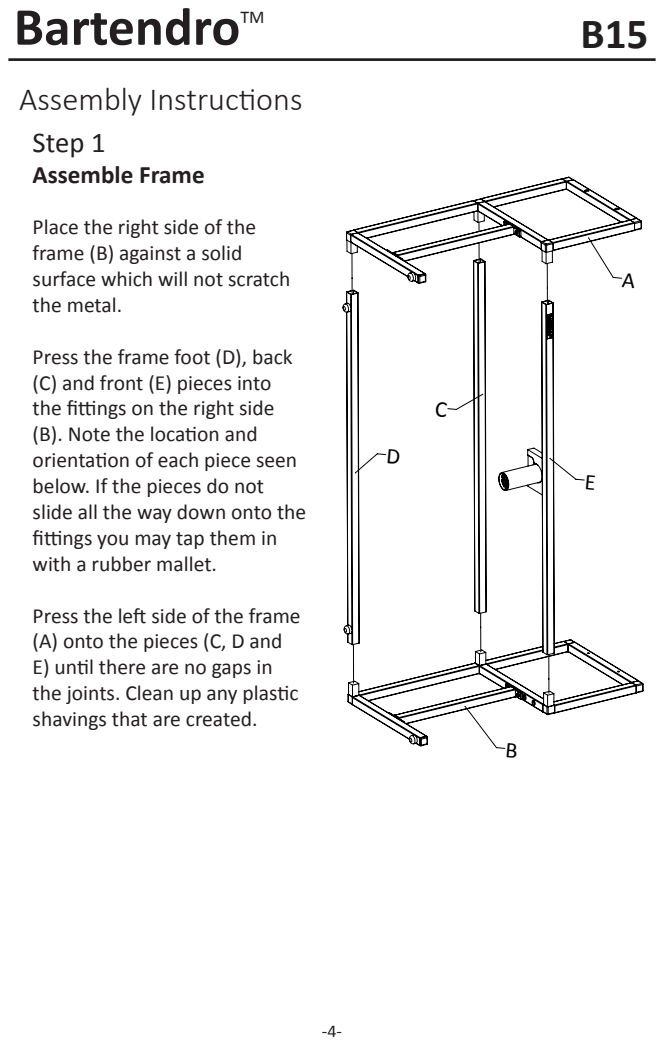
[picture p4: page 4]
Assemble Frame

Place the right side of the
frame (B) against a solid
surface which will not scratch
the metal.
Press the frame foot (D), back
(C) and front (E) pieces into
the fittings on the right side
(B). Note the location and
orientation of each piece seen
below. If the pieces do not
slide all the way down onto the
fittings you may tap them in
with a rubber mallet.
Press the left side of the frame
(A) onto the pieces (C, D and
E) until there are no gaps in
the joints. Clean up any plastic
shavings that are created.

## Step 2

Attach Housing to Frame

Place the completed frame upside-down onto a smooth, flat surface and place the housing in-between the frame as seen below.

Line up the 4 holes in the frame with the holes in the housing.

Attach the frame to the housing (F) using the screws (L) and a Phillips screwdriver.

Once the screws are tightened firmly, use the plugs (K) to cover the open holes.

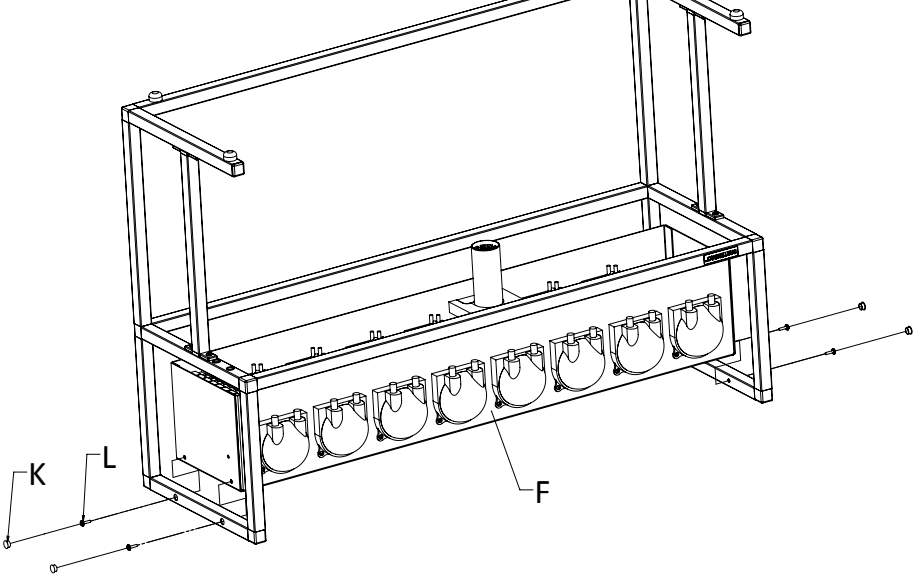
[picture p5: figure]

## Step 3

Attach Wire Clips (optional)

We’ve included some adhesive wire clips (I) to keep the power supply cable neatly tucked behind the frame.

Use the alcohol pad to clean the surface before you apply the clips so that they stick well.

Remove the backing, and attach where desired. You may use as many or as few as you like.

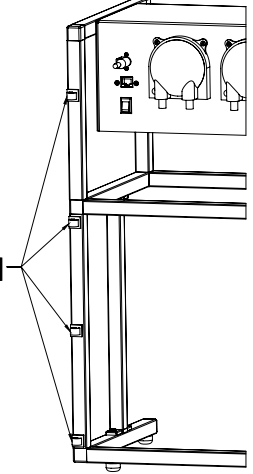
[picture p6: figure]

I

## Step 4

Plug in and Power On

Important: Before plugging the power supply into your bot, make sure the power switch is off. Plug the 4 pin connector into the bot first, then plug the AC power cord into a wall outlet. Turn the switch on and Bartendro will take approximately 1 minute to boot up.

Note: If the power supply experiences a fault while plugged in, its green light will turn off. Reset by unplugging it from the wall and plugging back in.
Bartendro is ready when the dispenser’s lights begin to fade in and out, changing color.
The status light on the right side of the bot will also turn green. This light will also serve to notify you when ingredients are low or out when the liquid sensors are enabled.

## Step 5

Install Input Tubing

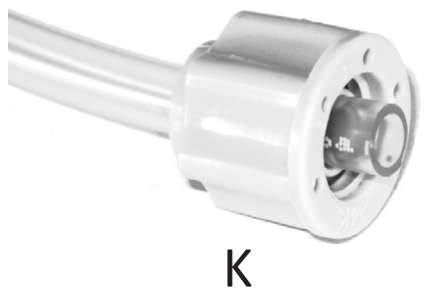
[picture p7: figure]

Find the bags labeled “Input Tubing for Front Row” and “Input Tubing for Back Row.”

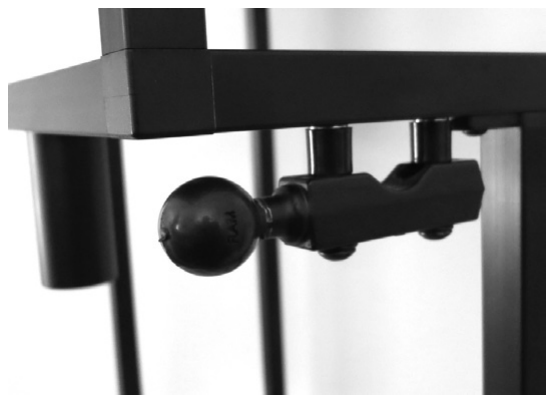
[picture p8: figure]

Feed the flat ends of these tubes through 15 compression nuts (K). Make sure the end of each tube sticks out of the nut by about 1/4” on the side of the nut that says “>PP<” on it.

If it’s hard to feed the tubing through the opening, try using the chopstick to widen it.

Turn each tube with compression nut
onto the right (input) port of each dispenser until it is finger tight. You should only see one or two threads remaining.

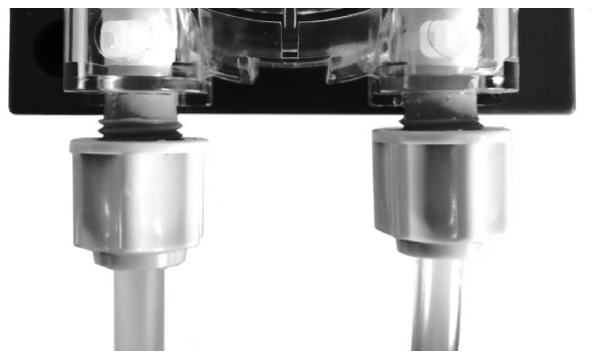
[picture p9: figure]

## Output Input

Note: Tablet Mounting (optional)
There are two holes on the right side of
the frame designed to fit RAM-B-309-1 from www.rammount.com. This part is not included, and if you use it, you will also need to get an arm and specific cradle for your device.

## Step 6

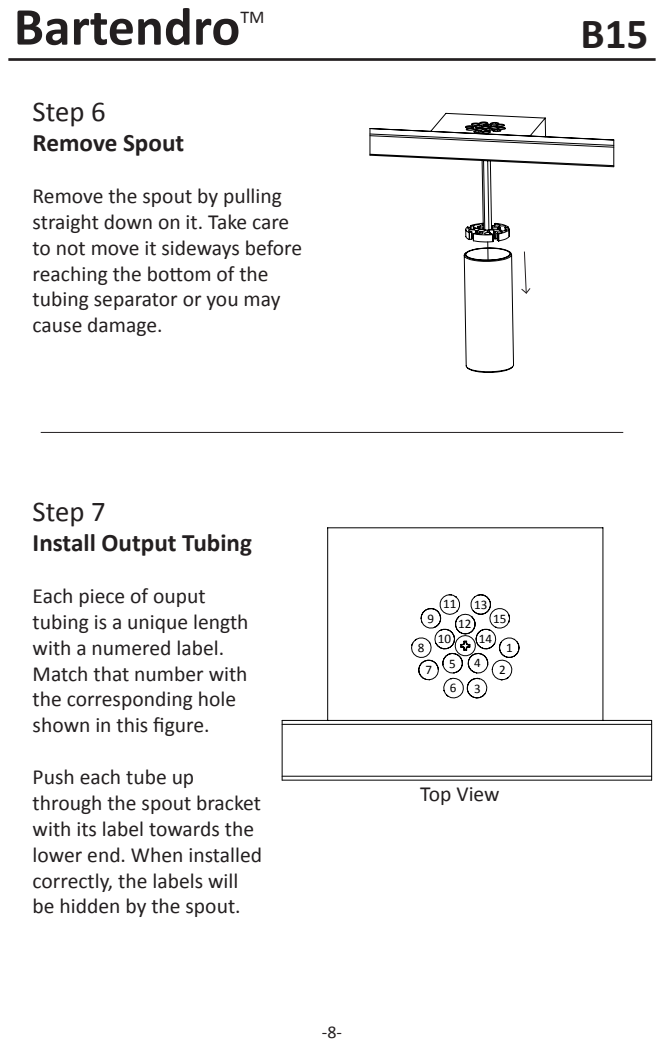
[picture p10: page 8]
Top View; Remove Spout

Remove the spout by pulling
straight down on it. Take care
to not move it sideways before
reaching the bottom of the
tubing separator or you may
cause damage.

Step 7
Install Output Tubing

Each piece of ouput
tubing is a unique length
with a numered label.
Match that number with
the corresponding hole
shown in this figure.
Push each tube up
through the spout bracket
with its label towards the
lower end. When installed
correctly, the labels will
be hidden by the spout.

## Step 8

Route Output Tubing

Repeat step 5 with the output tubing. This time install the tubes onto the left (output) port of each of dispenser.

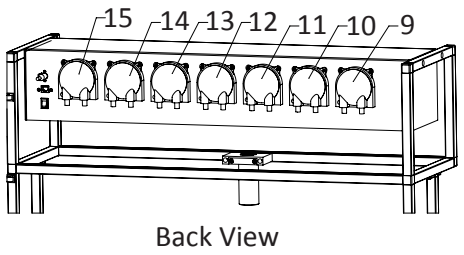
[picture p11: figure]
Back View

When you load ingredients
into the software interface
at a later step, these are the dispenser numbers that will be referred to.

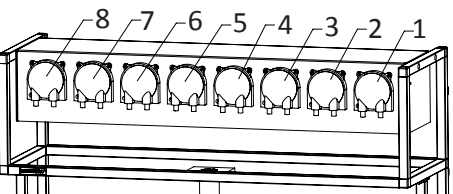
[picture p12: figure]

Front View

## Step 9

Spout Fine Tuning

Adjust the tubes near the the spout by pulling up or down so that they protrude by about 1/4” from the bottom of the tubing separator. It may be easiest to adjust the inner tubes (dispenser 4, 5, 10, 12, 14) first.

Return the spout by pushing it straight up into the bracket. Tighten or loosen the grip on the spout by adjusting the two screws.

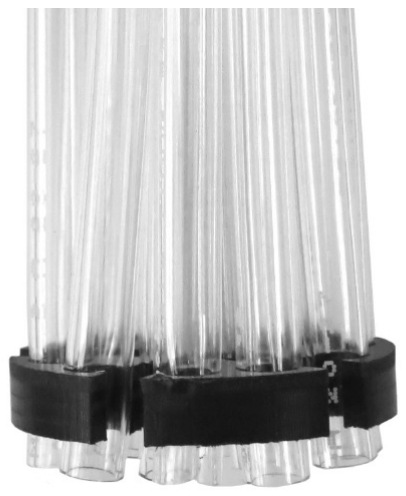
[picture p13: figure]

Adjustment
Screws

## Step 10

Install Sensor Tubing (optional)

Find the tubing labeled “Sensor Tubing for Front Row” and “Sensor Tubing for Back Row”.

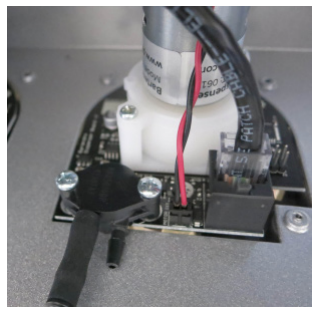
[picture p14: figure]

Install the clear tubing into the barbed fitting of each Level Sensor Tubing Adapter (N).

Install the open end of the adapter (N) to the left sensor port of each dispenser.

Liquid sensors can be enabled/disabled in the Admin Menu.

## Step 11

Attach Bottle Toppers and Sensor Tubing Keepers (optional)

Bottle Toppers (Q) and their Caps (P) are meant to keep fruit flies and dust out of your bottles.

The Bottle Topper Caps (P) have cutouts so that you can pass tubing through them. One for the input tube and one for the sensor tube.

Pass the tubing through (P) and (Q) first, then you can pass them through the Tubing Keepers (O). Space the tubing keeper about 1 inch from the bottom of the tubes.

N

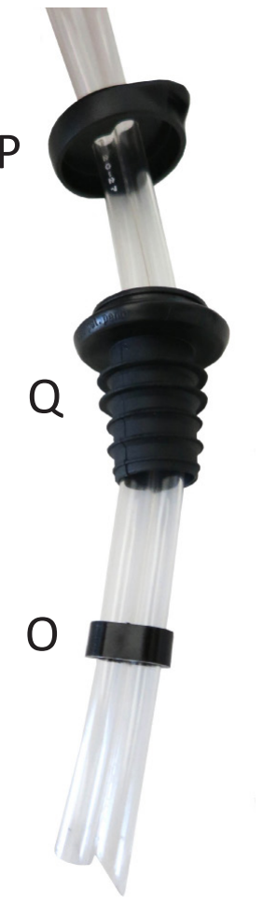
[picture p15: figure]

P

## Step 12

Insert Tubing into Bottles

Insert each dispenser’s input tube (with or without sensor tube) into an opened bottle until the tube(s) reach the bottom.

If using Bottle Toppers, press them down into the neck of the bottle until they are snug and snap the Bottle Topper Caps onto them.

## Connect to Bartendro

Find Network and Connect
Using a WiFi-enabled device, find the “bartendro” WiFi network by looking for it in your settings, and connect to it. The first time you connect may take as long as 30 seconds to establish the connection. Open Browser
iPhones and iPads will automatically display the Bartendro user interface (UI) soon after they connect to the Bartendro network. Users of Android and other devices will need to go to a web browser, like Chrome, type in any web address, and they will automatically be redirected to the Bartendro UI.

## Pour a Drink!

The main menu will display the drinks available to be served based on the ingredients selected for each dispenser. Each drink name is a button that you can press to select your drink. Once selected, you can make adjustments before pouring. Some drinks have different adjustment options depending on their ingredients.
The first time you dispense, you will not get a precise drink because the tubing will still have air in it. You should go to Admin > dispensers and turn on each dispenser until each tube has no air left in it. Pressing the ‘dispense 10mL’ button twice should do the trick. Don’t forget to put a glass under the spout!
To change the menu, create new drinks and edit way more settings, you need to login into the admin menu.

## Pour a Shot

Now you can create ad-hoc cocktails, or easily adjust cocktails after they’re made. The Shots tab in the upper left corner let’s you pour individual ingredients and can be enabled / disabled in the admin menu under options. You can also define your own shot size.

## Getting to the Admin Menu

To get to the Admin menu, touch or click the logo in the upper right corner of the screen.
When prompted use the default:
Name: bartendro
Password: boozemeup
Note: You can change the login name and password by going to the options tab once in the admin menu. Admin > options.
Admin
menu: This takes you to the main menu where drinks can be poured. dispensers: Select the ingredients you have loaded into Bartendro here. You can control the dispensers manually by pressing the ‘forward’, ‘reverse’ or ‘dispense’ buttons (useful for removing air from tubes). Add more ingredients in Admin > booze.
drinks: Create or modify existing drink recipes by selecting ingredients and their proportions. An ingredient’s number of parts is rounded to whole numbers. You must click ‘save’ for changes to take effect. booze: Edit and create your ingredients in this section. What you save here will be displayed in the pull-down menu in Admin > dispensers. options: Customize your settings by enabling or disabling many features here, including liquid level sensors and Shot mode. Follow the instructions on-screen to make your selections. You will need to press the ‘save and reboot’ button in order for changes to take effect. liquid level (if enabled): Calibrate the low and out threshold of the liquid level sensors by following the on-screen instructions.
debug: Use this tab if Bartendro is mis-behaving. You can see the communications logs and test dispenser connectivity. You will likely need to reference this tab if requesting support.

## Cleaning and Maintenance

For longest tube life, you should clean all of Bartendro’s tubing after every use.
Step 1
You will need three containers. Fill one with hot soapy water, one with clean water, and keep one empty for collecting discarded liquids.
Step 2
Go to Admin > dispensers, lift input tubing out of each bottle and use the ‘forward’ button to remove any remaining liquids from the tubes into your discard container. Repeat for each dispenser. A less sanitary approach is to use ‘reverse’ and pump unused liquids back into the bottles, but that’s up to you.
Step 3
Place the drained tubes in your container of hot soapy water and press the ‘clean’ button with your discard container under the spout. The button is located at the bottom of Admin > dispensers. This will run the dispenser long enough to wash out the tubes. Wipe down the outside of the tubing, tubing keepers and bottle toppers (if you are using them) while they are in the soapy water.
Step 4
Repeat Step 3 but with the container of clean water. Make sure to rinse the outside of the tubing as well. Sanitizing solutions like Star San (beer brewing sanitizer) may also be used. Do not use household chemicals.
Step 5
Finally, remove the tubes from the clean water and press the ‘clean’ or ‘forward’ button once more to empty the clean water from the tubing and prepare it for its next use. Pull down on the spout and clean the output tubing as necessary. A a narrow tube brush may be helpful.

Replace the inner beige dispenser tubing after about 500 hours of use (actual rotation time). If you plan on not using the bot for over a month, you should remove the beige tubing from the pump-head.

## Troubleshooting

Dispenser is blue / green / blank after power up
This is normal. The lights will remain in this mode until the Bartendro is booted and establishes a proper connection with the dispensers (which takes about one minute). If after a minute the lights don’t begin fading in and out, make sure the SD card is inserted properly.
Dispenser is flashing red
The dispenser has been over-worked and has been shut off to prevent damage. Check tubes for blockage and press the “reset” button under Admin > dispensers when they look clear. This will restore the dispenser to proper operation.
Air bubbles in tubes, or dripping
This is a sealing issue. You can try tightening the compression nuts first to see if they were just too loose. There should only be one or two threads visible. If that doesn’t fix it, then the tubing might not be protruding all the way through the compression nut (see page 5 for reference).
Main Menu doesn’t allow me to pour a drink
Check to make sure there are ingredients selected and saved under Admin > dispensers. Make sure either level sensor tubes are properly connected and submerged in liquid, or that liquid level sensors are disabled in Admin > options. Also, make sure there is a drink which can be made with your selected ingredients and that the “List this drink in the menu” option is selected in Admin > drinks for that drink.

## Getting Under the Hood — Advanced Users

If you know how to SSH into a machine and want to modify the behavior of your bot, you can do that by plugging an ethernet cable from Bartendro’s external Ethernet port into a wired networking router (wireless is disabled for security). Once connected, the credentials are: login as: bartendro
password: hackme!

Having Issues?
If you didn’t find what you were looking for in this manual, try some of these options:
- Search the forums at www.partyrobotics.com/forums. We en-courage you to post your questions so that others may learn from them.
- Check for up-to-date videos, manuals, and other guides at: www.partyrobotics.com/docs
- Email Us:
support@partyrobotics.com

Maker Warranty:
We’re here for you! If you have made modifications to your hardware or software and are having technical issues, we will be glad to attempt to resolve them with you. If an item was damaged in shipping, or is otherwise defective or malfunctioning, please email us right away and we will do our best to make things right on a case-by-case basis.

What are you waiting for?

Go make some drinks already!

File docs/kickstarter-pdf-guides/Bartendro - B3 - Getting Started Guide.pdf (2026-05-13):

# Getting Started Guide

BartendroTM | B3

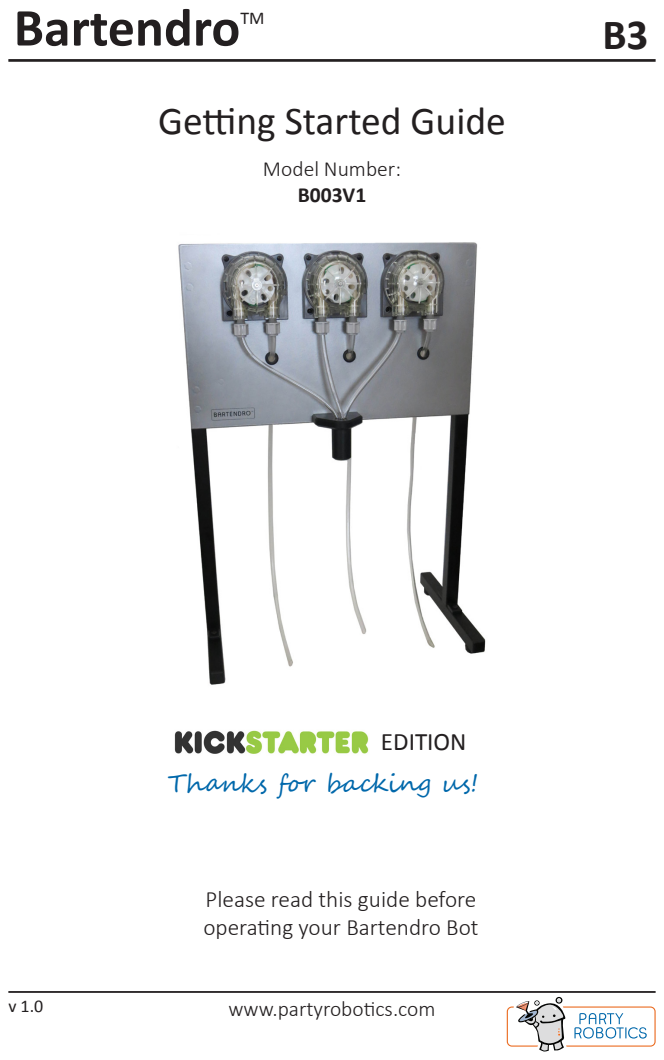
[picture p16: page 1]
Model Number: B003V1; EDITION

Thanks for backing us!

Please read this guide before
operating your Bartendro Bot

www.partyrobotics.com

Important Precautions

- Do not use Bartendro or its components for medical or life-critical applications.
- Avoid touching electronics when possible. The electronics in Bartendro may be damaged by static electricity, the sort your hands can pick up from shuffling your feet across the carpet. If you need to touch them, make sure to first discharge yourself by touching something metal connected to ground like a faucet or metal appliance.
- Plugging and unplugging Dispensers while the system is powered may cause permanent damage to your Bartendro.
- Powering the miniRouter board without the Raspberry Pi and Dispensers plugged in may cause permanent damage.
- Plug networking devices into the Raspberry Pi only. Plugging them into any other RJ45 connectors on the miniRouter Board will cause damage.
- It is not recommended to keep clear tubing immersed in liquid for extended periods of time. Doing so may cause discoloration, or cause mold to form.
- You may need to periodically recalibrate the Dispensers as the tubing wears. See www.partyrobotics.com/docs/ for instructions.
- If storing Bartendro for more than several weeks without use, we recommend removing the beige tubing from the Dispensers to extend tube life.
- Please drink and use responsibly.
You will need
Phillips screwdriver
Device with web browser (phone, tablet, laptop, etc.) Wired Networking Router (for software updates) Computer (for software updates)

Congratulations!

You are one of the first owners of the latest in cocktail dispensing technology. BartendroTM Cocktail Bots and Dispensers pour a variety of liquids precisely, and you can control them from phones or tablets. Whether you set up B3 to have a margarita night, or use it for mixing flavored syrups in your coffee, it will be sure to liven things up. What applications will you come up with? Please share your projects at: http://partyrobotics.com/forums/forum/sharing/

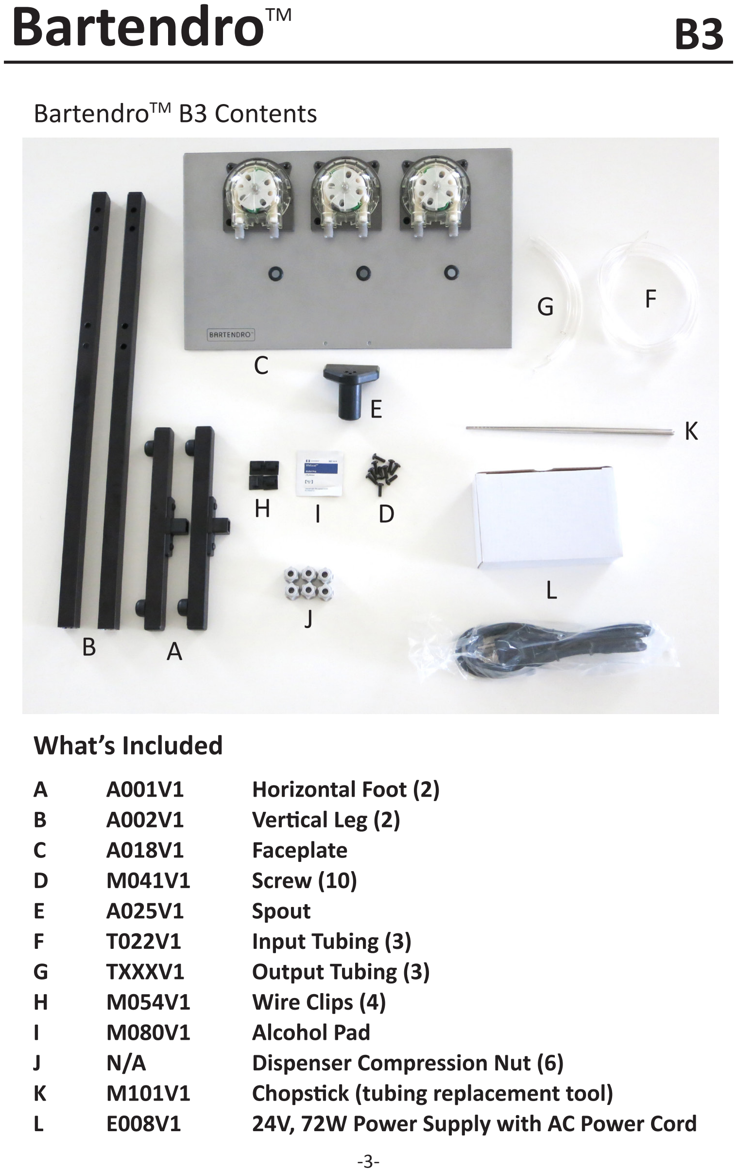
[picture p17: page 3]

B A

BartendroTM B3 Contents

What’s Included
A | A001V1 | Horizontal Foot (2)
B | A002V1 | Vertical Leg (2)
C | A018V1 | Faceplate
D | M041V1 | Screw (10)
E | A025V1 | Spout
F | T022V1 | Input Tubing (3)
G | TXXXV1 | Output Tubing (3)
H | M054V1 | Wire Clips (4)
I | M080V1 | Alcohol Pad
J | N/A | Dispenser Compression Nut (6)
K | M101V1 | Chopstick (tubing replacement tool)
L | E008V1 | 24V, 72W Power Supply with AC Power Cord

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
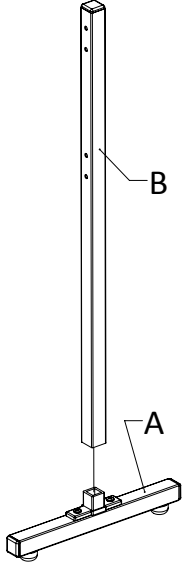
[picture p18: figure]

## Step 1

Build Frame Legs

Press vertical leg (B) onto the square fitting on the horizontal foot (A). Orientation of the holes should be in-line with the foot. Do this for both legs.

TIP: If the vertical leg is difficult to slide onto the fitting, try flipping it upside-down and resting it on a solid surface while using both hands to push down on the foot.

## Assembly Instructions

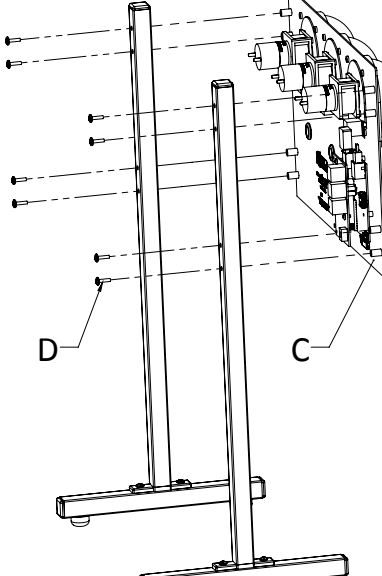
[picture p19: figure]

## Step 2

Attach Faceplate

The protrusions from the faceplate
(C) will fit into the large holes in the vertical legs.

Use 8 screws (D) to attach the faceplate to the legs.

## Step 3

Attach Spout

Use 2 screws (D) to attach the spout (E) to the faceplate (C)

## Step 4

Insert Tubes into Compression Nuts

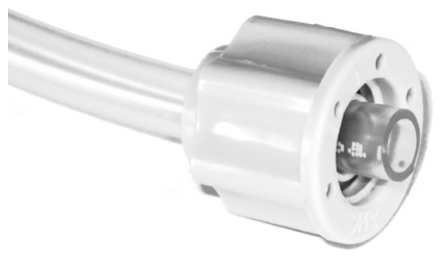
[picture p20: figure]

Feed the tubes through the compression nuts. Make sure the flat end of each tube sticks out of the nut by 1/8” on the side of the nut that says “>PP<” on it.

If the opening in the compression nut is too small, you can use the chopstick to widen it. Do this for all six tubes and nuts.

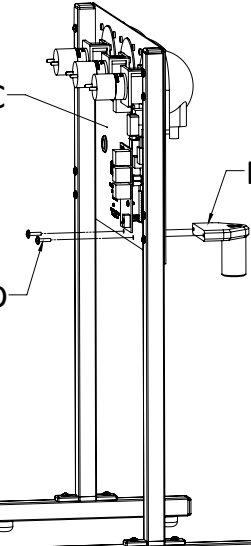
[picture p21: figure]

C
E

D

## Step 6

Attach Wire Clips (optional)

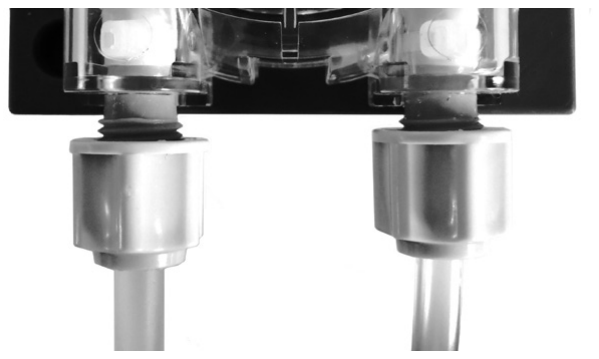
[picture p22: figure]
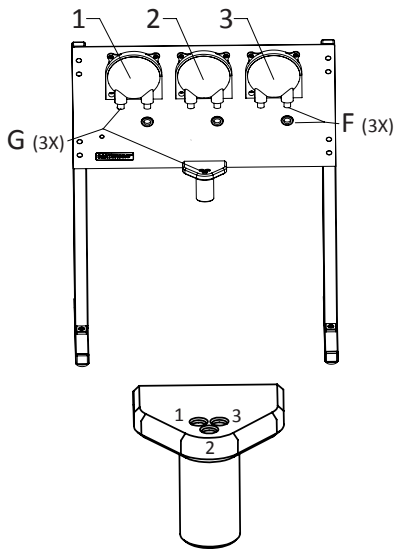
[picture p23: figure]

We’ve included some adhesive-backed wire clips (H) to keep the power supply cable neatly tucked behind the frame. Use the alcohol pad to clean the surface before you apply the clips so that they stick well. Remove the backing, and attach where desired. You may use as many or as few as you like.

## Step 5

Attach Tubing to Dispensers

Turn each tube / compression nut combo onto the Dispenser until they are finger tight. You should only see one or two threads remaining.

Attach the three longest tubes to the right side of each dispenser (F). Then feed them through the holes in the faceplate. These are the inputs tubes.

Attach the shorter output tubes to the left side of each dispenser (G). The longest of these goes to Dispenser 1, the second longest goes Dispenser 3, and the shortest to Dispenser 2.

Insert the output tubing into the spout until it reaches the bottom, but isn’t showing.

H

## Step 8

Insert Tubing into Bottle

While Bartendro is booting up, you can load your bottles for dispensing drinks.

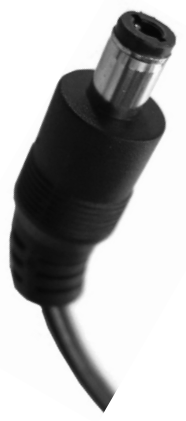
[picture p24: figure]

Insert the input tubes into the opened bottles so that they reach the bottom.

You’ll know Bartendro is ready when the Dispenser’s lights begin to fade in and out, changing color. It normally takes about 1 minute after plugging power in for the system to be ready to use.

If the lights stay a solid color, or don’t come on at all, see the Troubleshooting section on page 11.

## Step 7

Power Up

Important: Before plugging the AC power cord into the wall outlet, insert the DC plug (see image at right) into the miniRouter board.

Then plug the AC power cord into an outlet for Bartendro to begin booting. When the time comes to turn off Bartendro, start by unplugging the AC power cord from the wall first.

## Connect to Bartendro

Find Network and Connect
Using a WiFi-enabled device, find the “bartendro” WiFi network by looking for it in your settings, and connect to it. The first time you connect may take as long as 30 seconds to establish the connection. Open Browser
iPhones and iPads will automatically display the Bartendro user interface (UI) soon after they connect to the Bartendro network. Users of Android and other devices will need to go to a web browser like Chrome, type in any web address, and they will automatically be redirected to the Bartendro UI.

For Windows 7 users, if Bartendro is turned on and your computer is connected to the Bartendro network, but the browser does not load the page, you may need to change the following setting:
- Click Start (bottom left corner).
- Type “network connections” and hit enter.
- Right-click on Wireless Network Connection and select properties.
- Select Internet Protocol Version 4 and click the properties button.
- Make sure “obtain DNS server address automatically” is selected.

## Pour a Drink!

The main menu will display the current drinks available to be served. Each one is a button you can press to select your drink. Once selected, you can make adjustments before pouring. Some drinks have different adjustment options depending on their ingredients.
The first time you dispense, you will not get a precise drink because the tubing is not “primed,” meaning it still has air in it. You should go to Admin > dispensers and turn on each Dispenser until each tube has no air left in it. Don’t forget to put a glass under the spout.
To change the menu, create new drinks or modify your settings, you must log into the admin menu.

## Getting to the Admin Menu

To get to the Admin menu, find the hidden link at the bottom left corner of the main menu, or type “bartendro/admin” in the address bar of your browser.
When prompted use the default:
Name: bartendro
Password: boozemeup

Note: You can change the login name and password by going to Admin > options.
Admin
menu: This takes you to the main menu where drinks can be poured. dispensers: Select the ingredients you have loaded into Bartendro here. You can control the Dispensers manually by pressing the “turn on” or “dispense 10mL” buttons (useful for removing air from tubes). Add more ingredients in Admin > booze.
drinks: Create or modify existing drinks by selecting ingredients and the parts of that ingredient in the recipe. You must click “save” for changes to take effect.
booze: Edit and create your ingredients in this section. What you save here will be displayed in the pull-down menu in Admin > dispensers. options: Customize your settings by enabling or disabling many features here. Follow the instructions on-screen to make your selections. Your database file stores your settings and saved booze information. You can download this file and restore from it after a software update.
debug: Use this tab if Bartendro is mis-behaving. You can see the communications logs and test dispenser connectivity. You will likely need to reference this tab if requesting support.

## Cleaning and Maintenance

For longest tube life, you should clean all of Bartendro’s tubing after every use.
Step 1
You will need three tall containers or glasses. Fill one with hot soapy water, one with clean water, and keep the third one empty.
Step 2
Go to Admin > dispensers, lift input tubing out of the liquids and use the “turn on” button to drain the liquid from the tubes into your empty glass.
Step 3
Place the drained tubes in your container of hot soapy water and place your empty container under the spout, press the “clean” button. The button is located at the bottom of Admin > dispensers. This will run the dispenser long enough to wash out the tube. Wipe down the outside of the tubing while it is in the soapy water.
Step 4
Repeat step 3 but with the container of clean water. Sanitizing solutions like Star San (beer brewing sanitizer) may also be used. Do not use household chemicals. Make sure the outsides of to tubes get rinsed as well.
Step 5
Finally, remove the tubes from the clean water and press the “clean” or “turn on” button once more to empty the clean water from the tubing and prepare it for its next use.

You should replace the inner beige Dispenser tubing after 500 hours of use (actual rotation time). If you plan on not using the bot for over one month, you should remove the beige tubing from the pump-head. Instructions on doing this can be found at www.partyrobotics.com/ docs.

## Troubleshooting

Dispenser is blue / green / blank after power up
This is normal. The lights will remain in this mode until proper communication with Bartendro establishes a proper connection with the Dispensers (which takes about one minute). If after a minute the lights don’t begin fading in and out, make sure the SD card is inserted properly.
Dispenser is flashing red
The Dispenser has been over-worked and has been shut off to prevent damage. Check tubes for blockage and press the “reset” button under Admin > dispensers when they look clear. This will restore the Dispenser to proper operation.
Air bubbles in tubes, or dripping
This is a sealing issue. You can try tightening the compression nuts first to see if they were just too loose. There should only be one or two threads visible. If that doesn’t fix it, then the tubing might not be protruding all the way through the compression nut (see page 6 for reference).
Main Menu doesn’t allow me to pour a drink
Check to make sure there are ingredients selected and saved under Admin > dispensers. Make sure liquid level sensors are disabled in Admin > options. Also, make sure there is a drink which can be made with your selected ingredients and that the “List this drink in the menu” option is selected in Admin > drinks for that drink .

## Getting Under the Hood — Advanced Users

If you know how to SSH into a machine and want to modify the behavior of your bot, you can do that by plugging an ethernet cable from Bartendro’s Raspberry Pi into a wired networking router (wireless is disabled for security). Once connected, the credentials are:
login as: bartendro
password: hackme!

Having Issues?
If you didn’t find what you were looking for in this manual, try some of these options:
- Search the forums at www.partyrobotics.com/forums. We en-courage you to post your questions so that others may learn from them.
- Check for up-to-date videos, manuals, and other guides at: www.partyrobotics.com/docs
- Email Us:
support@partyrobotics.com

Maker Warranty:
We’re here for you! If you have made modifications to your hardware or software and are having technical issues, we will be glad to attempt to resolve them with you. If an item was damaged in shipping, or is otherwise defective or malfunctioning, please email us right away and we will do our best to make things right on a case-by-case basis.

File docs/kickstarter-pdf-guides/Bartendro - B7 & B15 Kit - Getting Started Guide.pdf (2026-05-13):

# BartendroTM

# Getting Started Guide

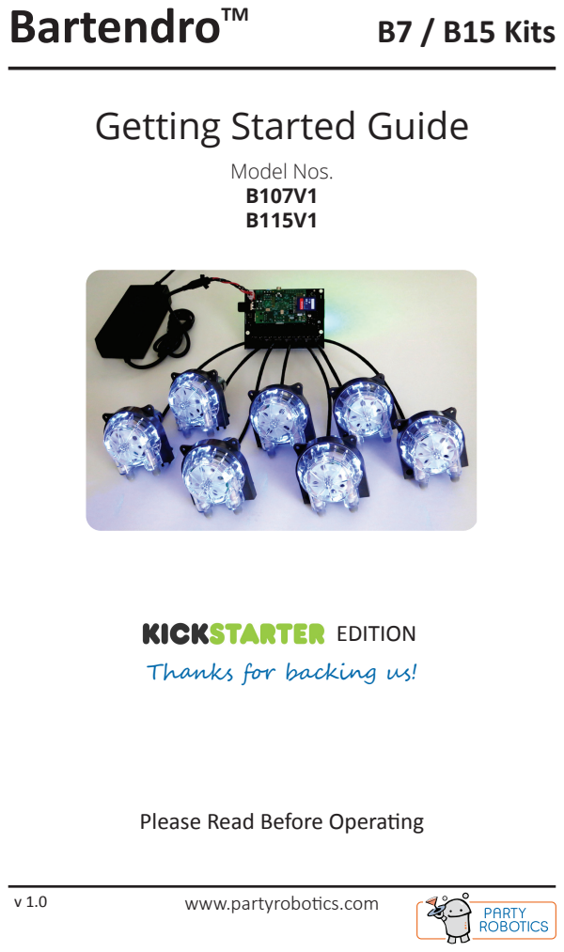
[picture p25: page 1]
Model Nos. B107V1 B115V1; B7 / B15 Kits; EDITION

Thanks for backing us!

Please Read Before Operating

www.partyrobotics.com

### Important Precautions

- Not intended for medical use.
- Electronics may be sensetive to static dissipation. Observe proper precautions for handling.
- It is not recommended to keep clear tubing immersed in liquid for extended periods of time.
- Beige tube (inside the Dispensers) life is approximated to be 500 hours of use.
- If storing long term without use, remove beige tubing from dispensers to extend tube life.
- Dispensers may need to be periodically re-calibrated as tubing wears.
- Please drink and use responsibly.

### Specifications

Max Flow rate: 700mL / min
Motor Operating Voltage: 24V
Minimum Dispense Volume: 2mL
Repeatability: ±1mL
Dispenser Current Consumption at 24V: 350mA Typical, 500mA max System Current Consumption at 24V: 0.5A Idle, 3A All dispensers on (B7) 0.5A Idle, 6A All dispensers on (B15) Max Cable Length to Router Board: 10ft

# BartendroTM

2 | www.partyrobotics.com

### Congratulations!

You are one of the first owners of a new enabling piece of technology. These precision BartendroTM Dispensers and electronics are the same as what go into BartendroTM cocktail bots. The applications don’t stop at cocktails though, people have been coming up with many applications from hydroponics to soap making. What will you come up with? Share your projects at: www.partyrobotics.com/community/sharing

# B7 / B15 Kits

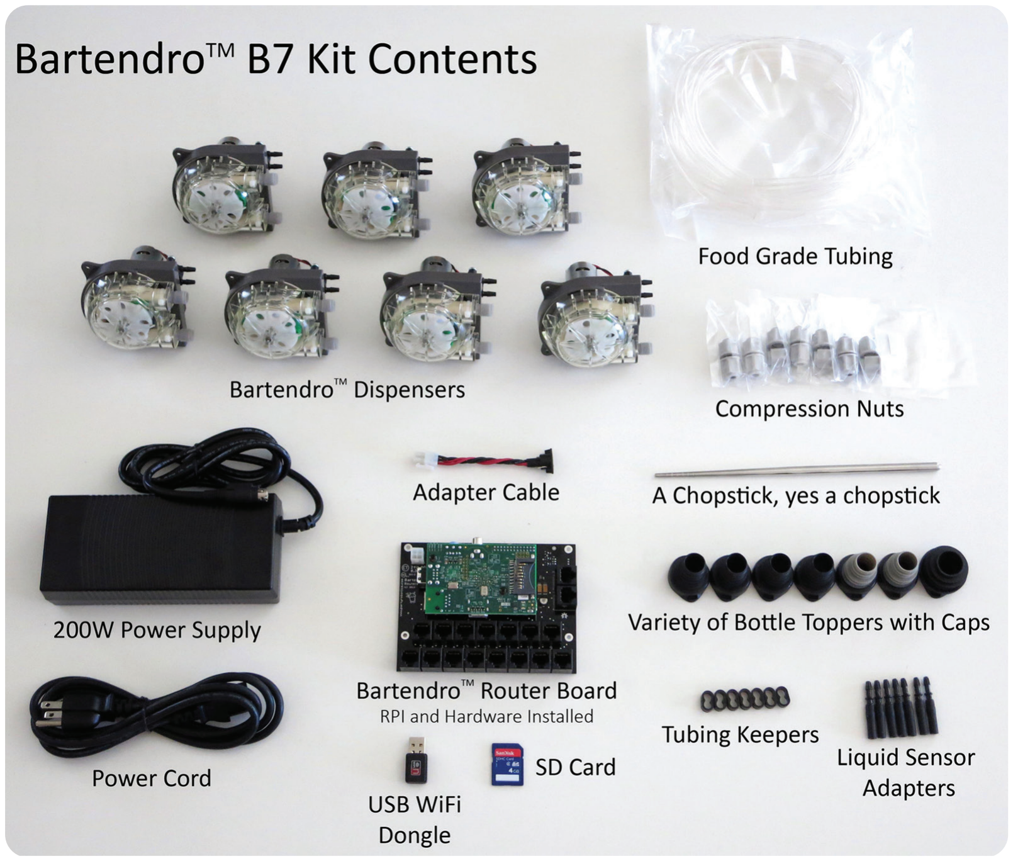
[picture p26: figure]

www.partyrobotics.com

# BartendroTM

3

### What’s Included:

B7 B15 Part No. Item
7 15 A007V1 BartendroTM Dispenser With Liquid Sense (includes two compression nuts)
1 | 1 | M101V1 A Chopstick (tubing replacement tool)
1 | 1 | A017V1 BartendroTM Router Board (with hardware)
1 | 1 | E004V1 Raspberry Pi (RPI)
1 | 1 | E007V1 SD Card
1 | 1 | E005V1 USB WiFi Dongle
1 | 1 | E009V1 24V, 200W Power Supply with Power Cord
1 | 1 | A014V1 Power Adapter Cable
1 | 1 | TXXXV1 Food Grade Tubing (about 5ft per dispenser)
4 | 8 | M102V1 Standard Bottle Topper
2 | 5 | M103V1 Large Bottle Topper
1 | 2 | M104V1 Extra Large Bottle Topper
7 | 15 M105V1 Bottle Topper Cap
7 | 15 M033V1 Tubing Keeper
7 | 15 A009V1 Liquid Sensor Adapter

# B7 / B15 Kits

### Quick Start Instructions

You will need:
AC Outlet
Device with Web Browser (phone, tablet, laptop, etc) Wired Networking Router (for software updates)
Computer (for software updates)

### Hardware Setup:

### 1. Make sure the Raspberry Pi is securely connected to the Router

Board and is supported with standoffs. Take care not to damage the header if removing the board. (gentle rocking works best)
2. Attach the provided SD Card and USB WiFi dongle to the RPI.

### 3. Connect Dispensers to the Router Board using the provided ether-

net cables. Note that ethernet cables are only used for convenience and commonality, the ethernet protocol is not used.

### 4. Port numbers on the Router Board should be noted when plugging

into a new Dispenser. The numbers can optionally be written down in the white box on the back of each dispenser.

### 5. Connect the Power Adapter Cable to the Router Board and the

Power Supply to an AC outlet. Mate both ends of the 4 pin connectors, the Raspberry Pi will begin to boot.

### 6. Once the Dispenser’s LEDs begin to fade in and out (about 1 min-

ute), the system is ready for use. If they don’t get to this state, see the Troubleshooting section on page 8.
7. Mount the dispensers appropriatly. See dimensions on page 7.
8. Attach clear tubing to the dispensers using the provided compres- sion nuts. Make sure to budget about 5ft per pump. Cut an angle into the bottom of the Dispenser’s input tubing to prevent it from attach- ing to the bottom of the bottles. See video at partyrobotics.com/docs.

### 9. Clear tubing cannot be attached directly to liquid sensors, so use

Liquid Sensor Adapters in between making sure to use the port that is farthest from the board. Use the black Tubing Keepers to keep both the Dispenser input tubing and liquid sensor tubing neatly together.

BartendroTM | B7 / B15 Kits

www.partyrobotics.com | 5

### Getting Started with the User Interface

Connect to your bot:

### 1. Using a WiFi enabled device, find the “bartendro” WiFi network by

looking for it in your settings and connect to it.

### 2. Once connected (up to ~30 sec the first time) you will need to go to

a web browser, such as Chrome, and type in any web addess. You will automatically be redirected to the Bartendro user interface (UI).

### 3. The main menu may or may not have drinks populated. To tell the

bot which ingredients are present, you will need to log into the admin screen. You may do this by either searching for the hidden link at the bottom left corner of the main menu, or typing bartendro/admin in the address bar of your browser.
When prompted use the default:
Name: bartendro
Password: boozemeup

Note: Your login name and password can be modified by changing a file on the Raspberry Pi. Instructions on page 7.
Once connected to Bartendro you will have access to the following:

### Admin

Admin - Dispensers: Controls ingredient selection for each dispenser from a drop down menu. Ingredients come from the “booze” tab. Choose wisely, your drink options depend on it! Note that taking manual control comes with responsibility. The “clean” button will indescriminitely dispense all of your booze if pressed by accident and you will be a sad panda. Each dispenser can indivudially be toggled on and off by using the “turn on”/”turn off” buttons and small incre- ments can be dispensed using the “dispense xxmL” button (helpful
when priming). The “liquid levels” button forces a check of liquid levels, but this only works if the feature is enabled. See page 7.
Admin - Drinks: Displays the drink list and allows you to make your own custom custom recipes. Select “add booze” and pick from the list of ingredients. The minimum number of parts is 1 and parts should be whole numbers, or will otherwise be rounded. All fields are required. Make sure to press save for your drink to be stored.

Admin - Booze: Displays the ingredient options and allows you to add your own custom ingredients. Adding the type, whether alcohol or sweetness / tartness will allow for customizations in the drink menu. Admin - Liquid Out: Liquid sensing is disabled by default. To turn this feature on, follow the steps on page 7. Once enabled, each dispenser can be tested by inserting the liquid sensor tubing into a shot glass of water. Type “90” as the threshold and press “go”. Slowly lift the sensor tubing out of the water to see where the “out” level is. This threshold can be changed in software.

### Main Menu

Menu: This is where your drinks are available for selection. The list automatically updates depending on what is loaded in the dispensers screen. Note that the menu may appear differently depending on the number of dispensers detected.
Menu - Drink Customization: After you select your drink from the menu a second screen will display allowing you to customize your drink. You will have the option to modify size, and depending on the ingredients, strength and sweeterness / tartness.

### Cleaning and Maintenance

All tubing should be cleaned regularly.

### 1. Empty what remains in the tubes by turning on the dispensers. You

may use the “turn on,” “dispense xxmL” or “clean” button to do this.

### 2. Fill a pitcher with hot soapy water and place the input tubes in it

after they’ve been drained. Press the “clean” button on the admin > dispensers screen and and this will cycle through each dispenser.
3. Repeat step 2 but with clean water in the pitcher. Sanitizing solu- tions may also be used.

### 4. Finally, run the clean cycle again with no liquids at the input. This

will empty the tubes of liquid and prepare it for its next use.

The inner, beige, dispenser tubing should be replaced after 500 hours of use, and removed if storing for prolonged periods of time.

### Getting under the hood:

There are several settings that aren’t exposed through the UI yet but can be changed by modifying the config.py file on the Raspberry Pi. Things like: use of liquid level sensors, display units, default size, taster buttons, the requirement to be logged in to dispense, etc.
To modify these settings:
1. Plug an ethernet cable from the RPI into a wired networking router. We’ve dissabled the ability to do this wirelessly for security reasons.

### 2. Use a terminal window on a Mac or Linux box, or use a program like

putty.exe in Windows to SSH into the bot. You may want to log into your networking router to discover the RPI’s IP address.
Once connected,
login as: bartendro
password: hackme!
You can use vi to edit:
bartendro@bartendro ~ $ vi bartendro/ui/config.py Save the file and power cycle for changes to take effect. See partyrobotics.com/docs for more detail.

### Dispenser Mounting Interface

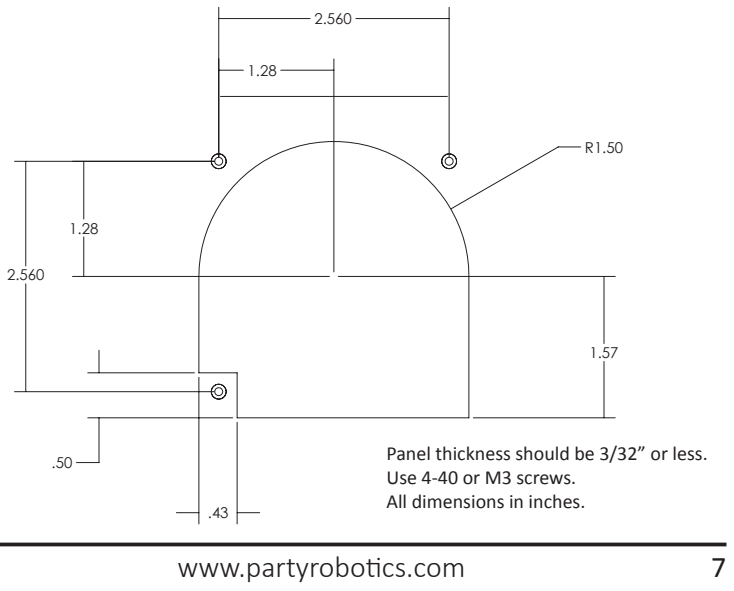
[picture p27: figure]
www.partyrobotics.com; Use 4-40 or M3 screws. All dimensions in inches.

.50 | Panel thickness should be 3/32” or less.

### Troubleshooting

Dispenser LEDs are blue and /or green after power up
This is normal, LEDs will remain in this mode until proper communication with dispensers is established (about 1 min). If not getting there, make sure SD card is properly seated Dispenser LEDs are flashing red
A current limit has been triggered on a dispenser, press the “reset” button in the admin > dispensers page to restore proper operation. Check tubes for blockage.
Air bubbles in tubes, or dripping
This is a sealing issue. Make sure tubing properly protrudes from the grey compression nuts by about 1/4”. The chopstick tool is handy for this. Make sure the compression nuts are tightened so that only one or two threads are visible.
Drinks not showing up in Main Menu
Check to make sure an ingredient is selected and saved for each dispenser and that there is a drink that uses those ingredients. If liquid level sensors are enabled, and the liquid level tubes are not inserted in liquid, or are in too little of liquid, the menu will be blank.

### Still Having Issues?

Try searching the forums at partyrobotics.com/forums. Post your questions so that others may learn from your issues. If stuck, email us at: support@partyrobotics.com
More documentation at:
www.partyrobotics.com/docs

### Warranty

We’re here for you! If you have made modifications to your hardware or software and are having technical issues, we will be glad to attempt to resolve them with you. If an item was damaged in shipping, or is otherwise defective or malfunctioning, please email us right away and we will do our best to make things right on a case-by-case basis.

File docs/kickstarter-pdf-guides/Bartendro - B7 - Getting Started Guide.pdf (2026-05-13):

# Getting Started Guide

BartendroTM | B7

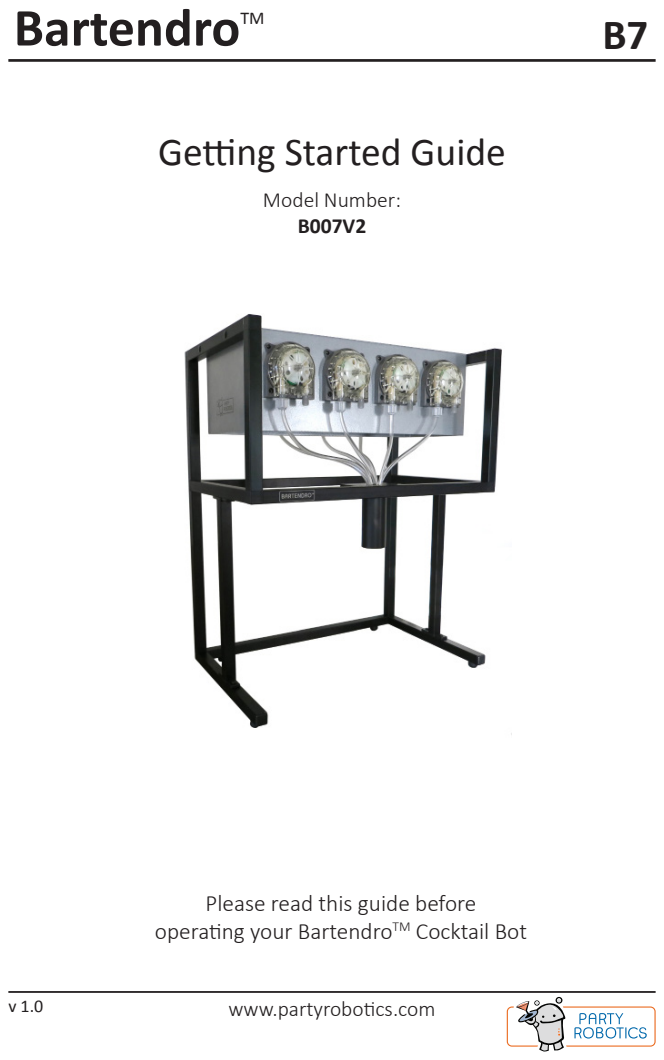
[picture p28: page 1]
Model Number: B007V2

Please read this guide before
operating your BartendroTM Cocktail Bot

www.partyrobotics.com

Important Precautions

- Do not use Bartendro or its components for medical or life-critical applications.
- Avoid touching electronics when possible. The electronics in Bartendro may be damaged by static electricity, the sort your hands can pick up from shuffling your feet across the carpet. If you need to touch them, make sure to first discharge yourself by touching something metal connected to ground like a faucet or metal appliance.
- Plugging and unplugging dispensers while the system is powered may cause permanent damage to your Bartendro.
- Powering the Router board without the Raspberry Pi and dispensers plugged in may cause permanent damage.
- Plug networking devices into the port available on the back of your Bartendro. Plugging them into any other RJ45 connector on the Router Board will cause damage.
- It is not recommended to keep clear tubing immersed in liquid for extended periods of time. Doing so may cause discoloration, or cause mold to form.
- If storing Bartendro for more than several weeks without use, we recommend removing the beige tubing from the dispensers to extend tube life.
- Please drink and use responsibly.

You will need
Phillips screwdriver
Device with web browser (phone, tablet, laptop, etc.) Wired Networking Router (for software updates) Computer (for software updates)

Congratulations!

You are one of the first owners of the latest in cocktail dispensing technology. BartendroTM Cocktail Bots and Dispensers pour a variety of liquids precisely, and you can control them from phones or tablets. Whether you set up your bot to host a party, or use it for mixing flavored syrups into sno-cones, it will be sure to liven things up. What applications will you come up with? Please share your projects at: http://partyrobotics.com/forums/forum/sharing/

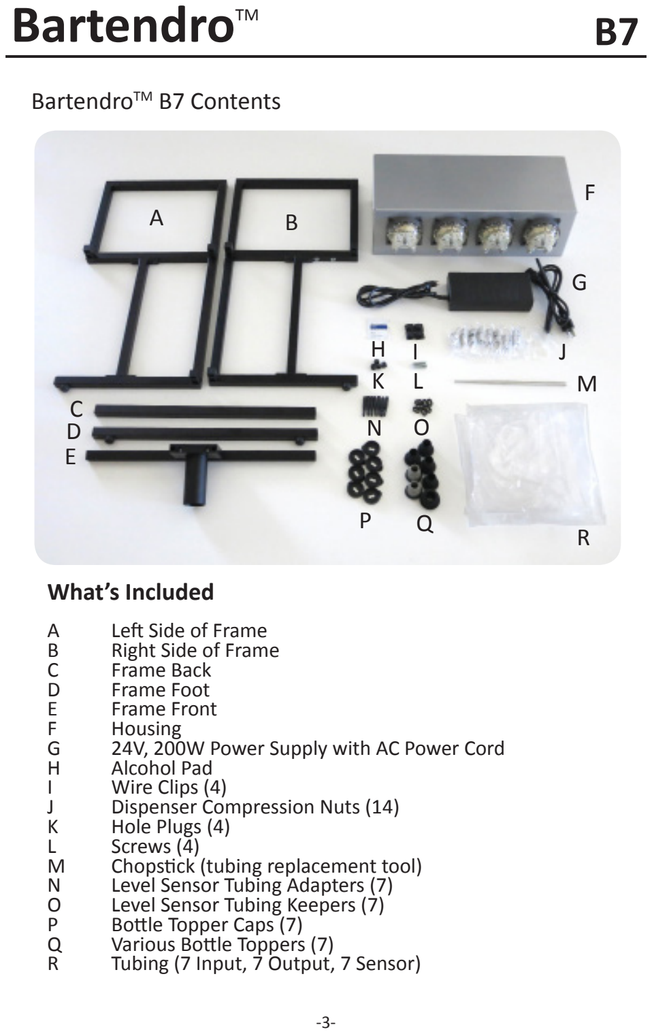
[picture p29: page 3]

BartendroTM B7 Contents

What’s Included
A | Left Side of Frame
B | Right Side of Frame
C | Frame Back
D | Frame Foot
E | Frame Front
F | Housing
G | 24V, 200W Power Supply with AC Power Cord
H | Alcohol Pad
I | Wire Clips (4)
J | Dispenser Compression Nuts (14)
K | Hole Plugs (4)
L | Screws (4)
M | Chopstick (tubing replacement tool)
N | Level Sensor Tubing Adapters (7)
O | Level Sensor Tubing Keepers (7)
P | Bottle Topper Caps (7)
Q | Various Bottle Toppers (7)
R | Tubing (7 Input, 7 Output, 7 Sensor)
A | B

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
Q | R

## Step 1

Assemble Frame

Place the right side of the frame (B) against a solid surface which will not scratch the metal.

Press the frame foot (D), back (C) and front (E) pieces into the fittings on the right side (B). Note the location and orientation of each piece seen below. If the pieces do not slide all the way down onto the fittings you may tap them in with a rubber mallet.

Press the left side of the frame (A) onto the pieces (C, D and E) until there are no gaps in the joints. Clean up any plastic shavings that are created.

## Assembly Instructions

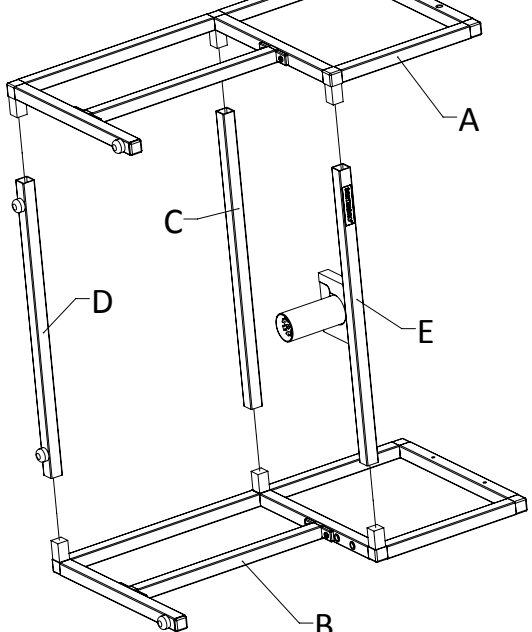
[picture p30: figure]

B

## Step 2

Attach Housing to Frame

Place the completed frame upside-down onto a smooth, flat surface and place the housing in-between the frame as seen below.

Line up the 4 holes in the frame with the holes in the housing.

Attach the frame to the housing (F) using the screws (L) and a Phillips screwdriver.

Once the screws are tightened firmly, use the plugs (K) to cover the open holes.

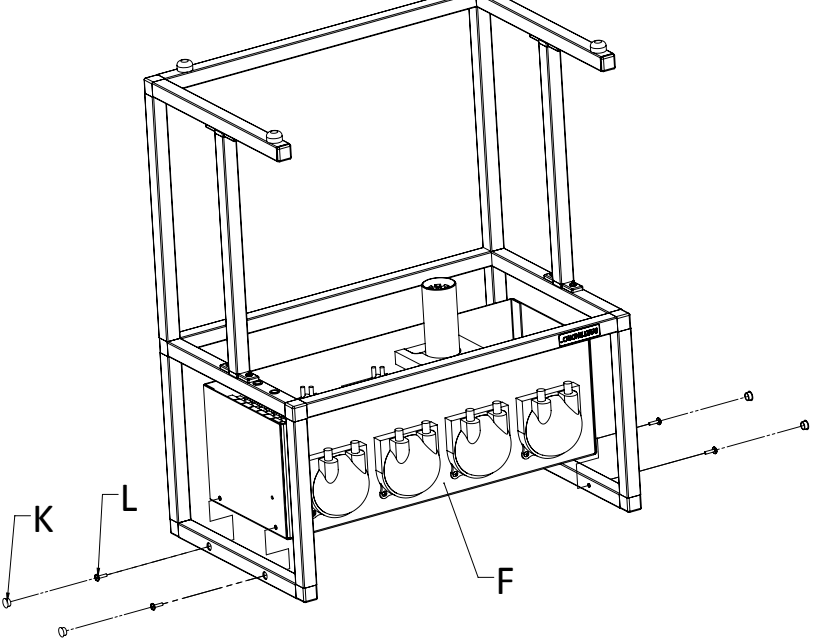
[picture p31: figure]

## Step 3

Attach Wire Clips (optional)

We’ve included some adhesive wire clips (I) to keep the power supply cable neatly tucked behind the frame.

Use the alcohol pad to clean the surface before you apply the clips so that they stick well.

Remove the backing, and attach where desired. You may use as many or as few as you like.

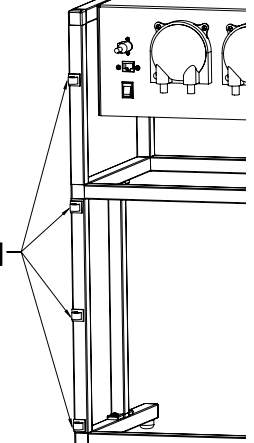
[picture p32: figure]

I

## Step 4

Plug in and Power On

Important: Before plugging the power supply into your bot, make sure the power switch is off. Plug the 4 pin connector into the bot first, then plug the AC power cord into a wall outlet. Turn the switch on and Bartendro will take approximately 1 minute to boot up.

Note: If the power supply experiences a fault while plugged in, its green light will turn off. Reset by unplugging it from the wall and plugging back in.
Bartendro is ready when the dispenser’s lights begin to fade in and out, changing color.
The status light on the right side of the bot will also turn green. This light will also serve to notify you when ingredients are low or out when the liquid sensors are enabled.

## Step 5

Install Input Tubing


Find the bags labeled “Input Tubing for Front Row” and “Input Tubing for Back Row.”


Feed the flat ends of these tubes through 7 compression nuts (K). Make sure the end of each tube sticks out of the nut by about 1/4” on the side of the nut that says “>PP<” on it.

If it’s hard to feed the tubing through the opening, try using the chopstick to widen it.

Turn each tube with compression nut
onto the right (input) port of each dispenser until it is finger tight. You should only see one or two threads remaining.


## Output Input

Note: Tablet Mounting (optional)
There are two holes on the right side of
the frame designed to fit RAM-B-309-1 from www.rammount.com. This part is not included, and if you use it, you will also need to get an arm and specific cradle for your device.

## Step 6

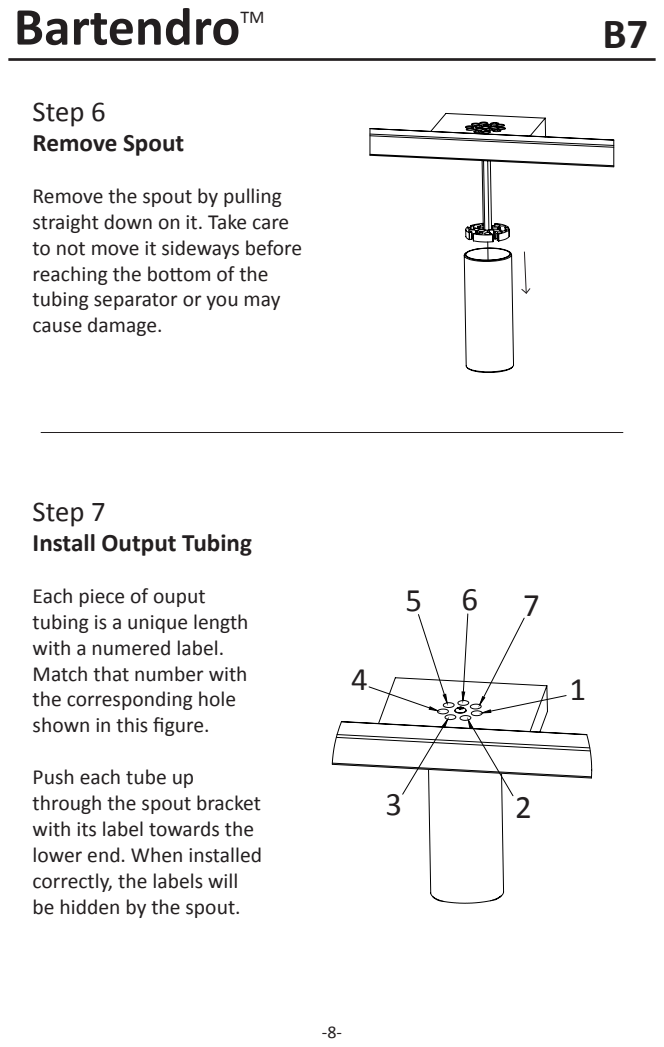
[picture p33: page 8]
Remove Spout

Remove the spout by pulling
straight down on it. Take care
to not move it sideways before
reaching the bottom of the
tubing separator or you may
cause damage.

Step 7
Install Output Tubing

Each piece of ouput
tubing is a unique length
with a numered label.
Match that number with
the corresponding hole
shown in this figure.
Push each tube up
through the spout bracket
with its label towards the
lower end. When installed
correctly, the labels will
be hidden by the spout.

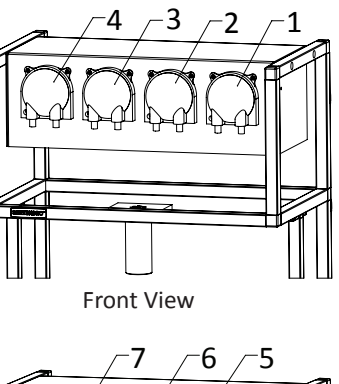
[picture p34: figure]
Front View

## Step 8

Route Output Tubing

Repeat step 5 with the output tubing. This time install the tubes onto the left (output) port of each of dispenser.

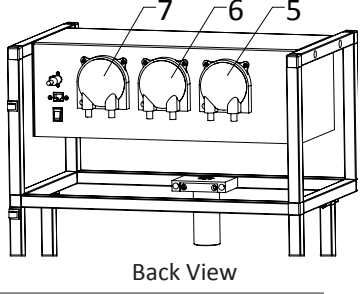
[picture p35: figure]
Back View

When you load ingredients
into the software interface
at a later step, these are the dispenser numbers that will be referred to.

## Step 9

Spout Fine Tuning

Adjust the tubes near the the spout by pulling up or down so that they protrude by about 1/4” from the bottom of the tubing separator.

Return the spout by pushing it straight up into the bracket. Tighten or loosen the grip on the spout by adjusting the two screws.

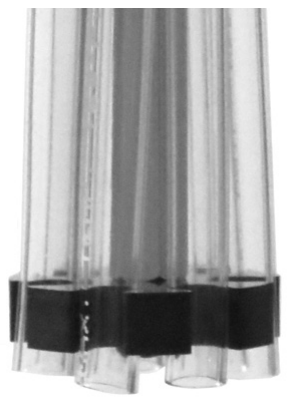
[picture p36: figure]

Adjustment
Screws

## Step 10

Install Sensor Tubing (optional)

Find the tubing labeled “Sensor Tubing for Front Row” and “Sensor Tubing for Back Row”.


Install the clear tubing into the barbed fitting of each Level Sensor Tubing Adapter (N).

Install the open end of the adapter (N) to the left sensor port of each dispenser.

Liquid sensors can be enabled/disabled in the Admin Menu.

## Step 11

Attach Bottle Toppers and Sensor Tubing Keepers (optional)

Bottle Toppers (Q) and their Caps (P) are meant to keep fruit flies and dust out of your bottles.

The Bottle Topper Caps (P) have cutouts so that you can pass tubing through them. One for the input tube and one for the sensor tube.

Pass the tubing through (P) and (Q) first, then you can pass them through the Tubing Keepers (O). Space the tubing keeper about 1 inch from the bottom of the tubes.

N


P

## Step 12

Insert Tubing into Bottles

Insert each dispenser’s input tube (with or without sensor tube) into an opened bottle until the tube(s) reach the bottom.

If using Bottle Toppers, press them down into the neck of the bottle until they are snug and snap the Bottle Topper Caps onto them.

## Connect to Bartendro

Find Network and Connect
Using a WiFi-enabled device, find the “bartendro” WiFi network by looking for it in your settings, and connect to it. The first time you connect may take as long as 30 seconds to establish the connection. Open Browser
iPhones and iPads will automatically display the Bartendro user interface (UI) soon after they connect to the Bartendro network. Users of Android and other devices will need to go to a web browser, like Chrome, type in any web address, and they will automatically be redirected to the Bartendro UI.

## Pour a Drink!

The main menu will display the drinks available to be served based on the ingredients selected for each dispenser. Each drink name is a button that you can press to select your drink. Once selected, you can make adjustments before pouring. Some drinks have different adjustment options depending on their ingredients.
The first time you dispense, you will not get a precise drink because the tubing will still have air in it. You should go to Admin > dispensers and turn on each dispenser until each tube has no air left in it. Pressing the ‘dispense 10mL’ button twice should do the trick. Don’t forget to put a glass under the spout!
To change the menu, create new drinks and edit way more settings, you need to login into the admin menu.

## Pour a Shot

Now you can create ad-hoc cocktails, or easily adjust cocktails after they’re made. The Shots tab in the upper left corner let’s you pour individual ingredients and can be enabled / disabled in the admin menu under options. You can also define your own shot size.

## Getting to the Admin Menu

To get to the Admin menu, touch or click the logo in the upper right corner of the screen.
When prompted use the default:
Name: bartendro
Password: boozemeup
Note: You can change the login name and password by going to the options tab once in the admin menu. Admin > options.
Admin
menu: This takes you to the main menu where drinks can be poured. dispensers: Select the ingredients you have loaded into Bartendro here. You can control the dispensers manually by pressing the ‘forward’, ‘reverse’ or ‘dispense’ buttons (useful for removing air from tubes). Add more ingredients in Admin > booze.
drinks: Create or modify existing drink recipes by selecting ingredients and their proportions. An ingredient’s number of parts is rounded to whole numbers. You must click ‘save’ for changes to take effect. booze: Edit and create your ingredients in this section. What you save here will be displayed in the pull-down menu in Admin > dispensers. options: Customize your settings by enabling or disabling many features here, including liquid level sensors and Shot mode. Follow the instructions on-screen to make your selections. You will need to press the ‘save and reboot’ button in order for changes to take effect. liquid level (if enabled): Calibrate the low and out threshold of the liquid level sensors by following the on-screen instructions.
debug: Use this tab if Bartendro is mis-behaving. You can see the communications logs and test dispenser connectivity. You will likely need to reference this tab if requesting support.

## Cleaning and Maintenance

For longest tube life, you should clean all of Bartendro’s tubing after every use.
Step 1
You will need three containers. Fill one with hot soapy water, one with clean water, and keep one empty for collecting discarded liquids.
Step 2
Go to Admin > dispensers, lift input tubing out of each bottle and use the ‘forward’ button to remove any remaining liquids from the tubes into your discard container. Repeat for each dispenser. A less sanitary approach is to use ‘reverse’ and pump unused liquids back into the bottles, but that’s up to you.
Step 3
Place the drained tubes in your container of hot soapy water and press the ‘clean’ button with your discard container under the spout. The button is located at the bottom of Admin > dispensers. This will run the dispenser long enough to wash out the tubes. Wipe down the outside of the tubing, tubing keepers and bottle toppers (if you are using them) while they are in the soapy water.
Step 4
Repeat Step 3 but with the container of clean water. Make sure to rinse the outside of the tubing as well. Sanitizing solutions like Star San (beer brewing sanitizer) may also be used. Do not use household chemicals.
Step 5
Finally, remove the tubes from the clean water and press the ‘clean’ or ‘forward’ button once more to empty the clean water from the tubing and prepare it for its next use. Pull down on the spout and clean the output tubing as necessary. A a narrow tube brush may be helpful.

Replace the inner beige dispenser tubing after about 500 hours of use (actual rotation time). If you plan on not using the bot for over a month, you should remove the beige tubing from the pump-head.

## Troubleshooting

Dispenser is blue / green / blank after power up
This is normal. The lights will remain in this mode until the Bartendro is booted and establishes a proper connection with the dispensers (which takes about one minute). If after a minute the lights don’t begin fading in and out, make sure the SD card is inserted properly.
Dispenser is flashing red
The dispenser has been over-worked and has been shut off to prevent damage. Check tubes for blockage and press the “reset” button under Admin > dispensers when they look clear. This will restore the dispenser to proper operation.
Air bubbles in tubes, or dripping
This is a sealing issue. You can try tightening the compression nuts first to see if they were just too loose. There should only be one or two threads visible. If that doesn’t fix it, then the tubing might not be protruding all the way through the compression nut (see page 5 for reference).
Main Menu doesn’t allow me to pour a drink
Check to make sure there are ingredients selected and saved under Admin > dispensers. Make sure either level sensor tubes are properly connected and submerged in liquid, or that liquid level sensors are disabled in Admin > options. Also, make sure there is a drink which can be made with your selected ingredients and that the “List this drink in the menu” option is selected in Admin > drinks for that drink.

## Getting Under the Hood — Advanced Users

If you know how to SSH into a machine and want to modify the behavior of your bot, you can do that by plugging an ethernet cable from Bartendro’s external Ethernet port into a wired networking router (wireless is disabled for security). Once connected, the credentials are: login as: bartendro
password: hackme!

Having Issues?
If you didn’t find what you were looking for in this manual, try some of these options:
- Search the forums at www.partyrobotics.com/forums. We en-courage you to post your questions so that others may learn from them.
- Check for up-to-date videos, manuals, and other guides at: www.partyrobotics.com/docs
- Email Us:
support@partyrobotics.com

Maker Warranty:
We’re here for you! If you have made modifications to your hardware or software and are having technical issues, we will be glad to attempt to resolve them with you. If an item was damaged in shipping, or is otherwise defective or malfunctioning, please email us right away and we will do our best to make things right on a case-by-case basis.

What are you waiting for?

Go make some drinks already!

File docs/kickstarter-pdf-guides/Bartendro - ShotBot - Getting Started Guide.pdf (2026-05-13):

# Getting Started Guide

BartendroTM | ShotBot

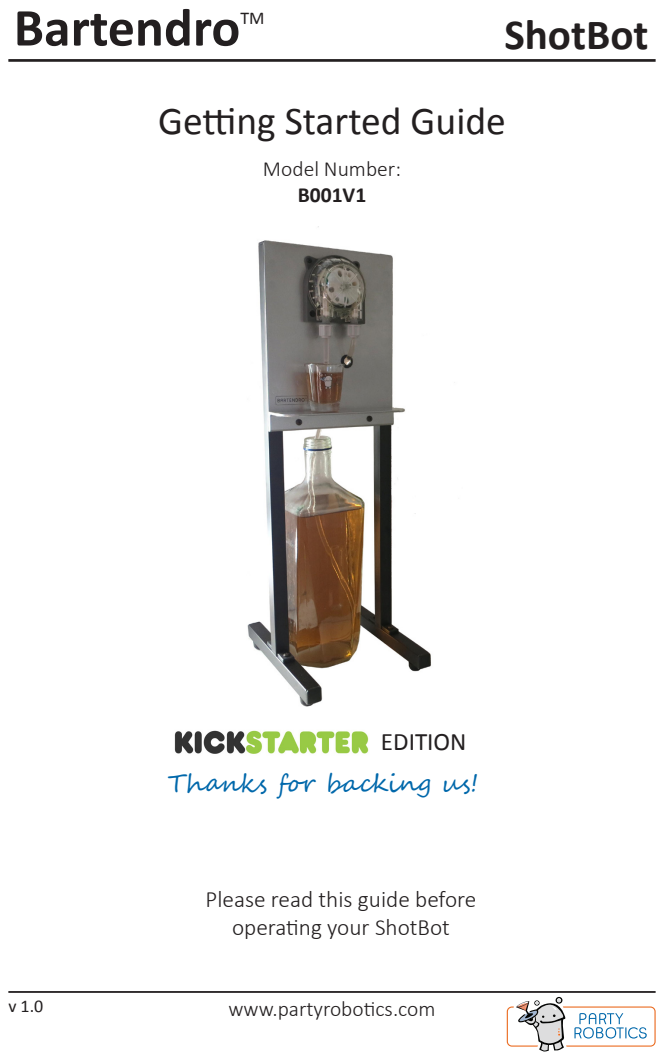
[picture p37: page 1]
Model Number: B001V1; EDITION

Thanks for backing us!

Please read this guide before
operating your ShotBot

www.partyrobotics.com

Important Precautions

- Do not use Bartendro or its components for medical or life-critical applications.
- Avoid touching electronics when possible. The electronics in Bartendro may be damaged by static electricity, the sort your hands can pick up from shuffling your feet across the carpet. If you need to touch them, make sure to first discharge yourself by touching something metal connected to ground like a faucet or metal appliance.
- Plugging and unplugging Dispensers while the system is powered may cause permanent damage to your Bartendro.
- Powering the miniRouter board without the Raspberry Pi and Dispenser plugged in may cause permanent damage.
- Plug networking devices into the Raspberry Pi only. Plugging them into any other RJ45 connectors on the miniRouter Board will cause damage.
- It is not recommended to keep clear tubing immersed in liquid for extended periods of time. Doing so may cause discoloration, or cause mold to form.
- You may need to periodically recalibrate the Dispensers as the tubing wears. See www.partyrobotics.com/docs/ for instructions on how to recalibrate them.
- If storing Bartendro for more than several weeks without use, we recommend removing the beige tubing from the Dispensers to extend tube life.
- Please drink and use responsibly.
You will need
Phillips screwdriver
Device with web browser (phone, tablet, laptop, etc.) Wired Networking Router (for software updates) Computer (for software updates)

Congratulations!

You are one of the first owners of the latest in cocktail dispensing technology. BartendroTM Cocktail Bots and Dispensers pour a variety of liquids precisely, and you can control them from phones or tablets. Whether you set up ShotBot to remind you to drink your water, or use it for a quick round of no-mess shots, it will be sure to liven things up. What applications will you come up with? Share your projects at: http://partyrobotics.com/forums/forum/sharing/

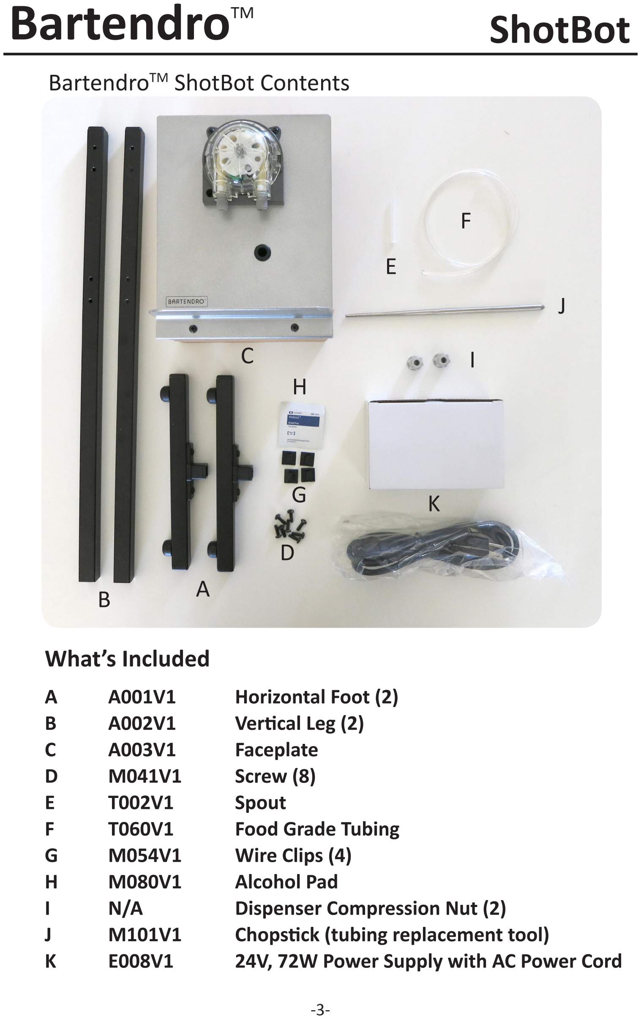
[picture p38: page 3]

A B

BartendroTM ShotBot Contents

What’s Included
A | A001V1 | Horizontal Foot (2)
B | A002V1 | Vertical Leg (2)
C | A003V1 | Faceplate
D | M041V1 | Screw (8)
E | T002V1 | Spout
F | T060V1 | Food Grade Tubing
G | M054V1 | Wire Clips (4)
H | M080V1 | Alcohol Pad
I | N/A | Dispenser Compression Nut (2)
J | M101V1 | Chopstick (tubing replacement tool)
K | E008V1 | 24V, 72W Power Supply with AC Power Cord

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
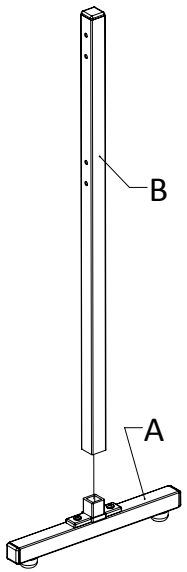
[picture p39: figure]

## Step 1

Build Frame Legs

Press vertical leg (B) onto the square fitting on the horizontal foot (A). Orientation of the holes should be in-line with the foot. Do this for both legs.

TIP: If the vertical leg is difficult to slide onto the fitting, try flipping it upside-down and resting it on a solid surface while using both hands to push down on the foot.

## Assembly Instructions

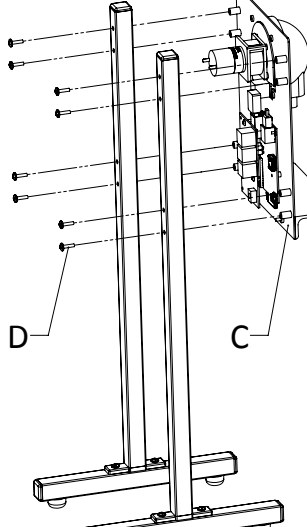
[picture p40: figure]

## Step 2

Attach Faceplate

The protrusions from the faceplate
(C) will fit into the large holes in the vertical legs.

Use the 8 screws (D) to attach the faceplate to the legs.

Note: If you would like to accommodate taller shot glasses, you can either cut the spout so that it is shorter, or remove the shelf where shot glasses rest and and re-attach upside-down.

## Step 3

Install Tubing and Spout

1) Feed the rigid spout and flexible tubing through the compression nuts. The end with the angled cut goes into bottles and the flat end towards the dispenser.

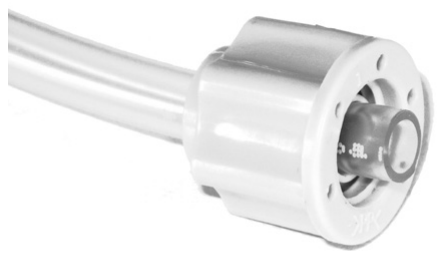
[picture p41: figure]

Make sure the tubing goes all the way through the nut and sticks out by about 1/8” on the side that says “>PP<” on it. If the opening in the compression nut is too small, you can use the chopstick to widen it.


2) Attach the 2 inch, rigid spout on the left side of ShotBot (E) and attach the flexible tubing on the right (F).
3) Tighten compression nuts so that there are only one or two threads showing.


4) Feed the flexible tubing through the opening in the metal (F).


## Step 5

Attach Wire Clips (optional)


We’ve included some adhesive wire clips to keep the power supply cable neatly tucked next to the frame.

Use the alcohol pad to clean the surface before you apply the clips (G) so that they stick well. Remove the backing, and attach where desired. You may use as many or as few as you like.

## Step 4

Insert SD Card

While looking at the back of ShotBot, hold the SD card with the pins facing you and carefully insert into the slot on the back side of the Raspberry Pi board.

It will hang out a little bit. This is okay.

## Step 6

Power Up


Important: Before plugging the AC power cord into the wall outlet, insert the DC plug (see image at right) into the miniRouter board.

Then plug the AC power cord into an outlet for Bartendro to begin booting. When the time comes to turn off Bartendro, start by unplugging the AC power cord from the wall first.

## Step 7

Insert Tubing into Bottle

While Bartendro is booting up, you can load your bottle for dispensing shots.

Insert the long flexible tube into an opened bottle so that it reaches the bottom.

You’ll know Bartendro is ready when the Dispenser’s lights begin to fade in and out, changing color. It normally takes about 1 minute after plugging power in for the system to be ready to use.

If the lights stay a solid color, or don’t come on at all, see the Troubleshooting section on page 11.

## Connect to Bartendro

Find Network and Connect
Using a WiFi-enabled device, find the “bartendro” WiFi network by looking for it in your settings, and connect to it. The first time you connect may take as long as 30 seconds to establish the connection. Open Browser
iPhones and iPads will automatically display the Bartendro user interface (UI) soon after they connect to the Bartendro network. Users of Android and other devices will need to go to a web browser like Chrome, type in any web address, and they will automatically be redirected to the Bartendro UI.

For Windows 7 users, if Bartendro is turned on and your computer is connected to the Bartendro network, but the browser does not load the page, you may need to change the following setting:
- Click Start (bottom left corner).
- Type “network connections” and hit enter.
- Right-click on Wireless Network Connection and select properties.
- Select Internet Protocol Version 4 and click the properties button.
- Make sure “obtain DNS server address automatically” is selected.

## Pour a Shot!

The main menu will display the current ingredient being served and a button you can press to pour your shot. Go ahead, give it a shot!
The first time you dispense, be aware that the tubing is still full of air, so you will not get the full amount displayed.
To change the ingredient displayed or the default shot size you will need to go to Admin > dispensers by first logging into the admin menu, see next page.

## Getting to the Admin Menu

To get to the Admin menu, find the hidden link at the bottom left corner of the main menu, or type “bartendro/admin” in the address bar of your browser.
When prompted use the default:
Name: bartendro
Password: boozemeup

Note: You can change the login name and password by going to Admin > options.
Admin
menu: This takes you to the main menu where shots can be poured. dispensers: Select the ingredient you have loaded into Bartendro here. You can control the Dispenser manually by pressing the “turn on” or “dispense 10mL” buttons. Add more ingredients in Admin > booze. drinks: Ignore this tab, it is only useful if there is more than one Dispenser present.
booze: Edit and create your ingredients in this section. What you save here will be displayed in the pull-down menu in Admin > dispensers. options: Customize your settings by enabling or disabling many features here. Follow the instructions on-screen to make your selections. Some options may not be applicable to ShotBot. Your database file stores your settings and saved booze information. You can download this file and restore from it after a software update.
debug: Use this tab if Bartendro is mis-behaving. You can see the communications logs and test dispenser connectivity. You will likely need to reference this tab if requesting support.

## Cleaning and Maintenance

For longest tube life, you should clean all of Bartendro’s tubing after every use.
Step 1
Get three tall glasses or containers. Fill one with hot soapy water, one with clean water, and keep the third one empty.
Step 2
Go to Admin > dispensers, lift the flexible tubing out of the liquid or bottle that it’s in and use the “turn on” button to drain the liquid from the tubing into your empty glass.
Step 3
Place the drained tube in your container of hot soapy water and while holding your empty glass under the spout, press the “clean” button. The button is located at the bottom of Admin > dispensers. This will run the dispenser long enough to wash out the tube.
Step 4
Repeat step 3 but with the glass of clean water. Sanitizing solutions like Star San (beer brewing sanitizer) may also be used. Do not use household chemicals.
Step 5
Finally, remove the tubes from the clean water and press the “clean” or “turn on” button once more to empty the clean water from the tubing and prepare it for its next use.

You should replace the inner beige Dispenser tubing after 500 hours of use (actual rotation time). If you plan on not using the bot for over one month, you should remove the beige tubing from the pump-head. Instructions on doing this can be found at www.partyrobotics.com/ docs.

## Troubleshooting

Dispenser is blue / green / blank after power up
This is normal. The lights will remain in this mode until proper communication with Bartendro establishes a proper connection with the Dispenser(s) (which takes about one minute). If after a minute the lights don’t begin fading in and out, make sure the SD card is inserted properly.
Dispenser is flashing red
The Dispenser has been over-worked and has been shut off to prevent damage. Check tubes for blockage and press the “reset” button under Admin > dispensers when they look clear. This will restore the Dispenser to proper operation.
Air bubbles in tubes, or dripping
This is a sealing issue. You can try tightening the compression nuts first to see if they were just too loose. There should only be one or two threads visible. If that doesn’t fix it, then the tubing might not be protruding all the way through the compression nut (see page 5 for reference).
Main Menu doesn’t allow me to pour a shot
Check to make sure there is an ingredient selected and saved under Admin > dispensers. Also, make sure liquid level sensors are disabled in Admin > options.

## Getting Under the Hood — Advanced Users

If you know how to SSH into a machine and want to modify the behavior of your bot, you can do that by plugging an ethernet cable from Bartendro’s Raspberry Pi into a wired networking router (wireless is disabled for security). Once connected, the credentials are:

login as: bartendro
password: hackme!

Having Issues?
If you didn’t find what you were looking for in this manual, try some of these options:
- Search the forums at www.partyrobotics.com/forums. We en-courage you to post your questions so that others may learn from them.
- Check for up-to-date videos, manuals, and other guides at: www.partyrobotics.com/docs
- Email Us:
support@partyrobotics.com

Maker Warranty:
We’re here for you! If you have made modifications to your hardware or software and are having technical issues, we will be glad to attempt to resolve them with you. If an item was damaged in shipping, or is otherwise defective or malfunctioning, please email us right away and we will do our best to make things right on a case-by-case basis.

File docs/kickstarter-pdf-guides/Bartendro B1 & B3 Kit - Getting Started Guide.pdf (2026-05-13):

# BartendroTM

# Getting Started Guide

Model Nos. B101V1 B103V1; B1 / B3 Kits; EDITION

Thanks for backing us!

Please Read Before Operating

www.partyrobotics.com

### Important Precautions

- Not intended for medical use.
- Electronics may be sensetive to static dissipation. Observe proper precautions for handling.
- It is not recommended to keep clear tubing immersed in liquid for extended periods of time.
- Beige tube (inside the Dispensers) life is approximated to be 500 hours of use.
- If storing long term without use, remove beige tubing from dispensers to extend tube life.
- Dispensers may need to be periodically re-calibrated as tubing wears.
- Please drink and use responsibly.

### Specifications

Max Flow rate: 700mL / min
Motor Operating Voltage: 24V
Minimum Dispense Volume: 2mL
Repeatability: ±1mL
Dispenser Current Consumption at 24V: 350mA Typical, 500mA max System Current Consumption at 24V: 0.5A Idle, 1A All dispensers on (B1) 0.5A Idle, 2A All dispensers on (B3) Max Cable Length to Router Board: 10ft

# BartendroTM

2 | www.partyrobotics.com

### Congratulations!

You are one of the first owners of a new enabling piece of technology. These precision BartendroTM Dispensers and electronics are the same as what go into BartendroTM cocktail bots. The applications don’t stop at cocktails though, people have been coming up with many ideas from hydroponics to sno-cones. What will you come up with? Share your projects at: www.partyrobotics.com/community/sharing

# B1 / B3 Kits

Power Cord; BartendroTM Dispensers; 72W Power Supply; BartendroTM miniRouter Board with mounting hardware; Chopstick; Food Grade Tubing & Compression Nuts; 2ft Ethernet Cables SD Card USB Wifi Dongle

www.partyrobotics.com

# BartendroTM

3

### What’s Included:

B1 B3 Part No. Item
1 | 3 | A007V1 BartendroTM Dispenser (includes two compression nuts)
1 | 1 | M101V1 Chopstick (tubing replacement tool)
1 | 1 | A016V1 BartendroTM miniRouter Board
| | (with hardware to mount Raspberry Pi)
1 | 1 | E007V1 SD Card
1 | 1 | E005V1 USB WiFi Dongle
1 | 1 | E008V1 24V, 72W Power Supply & Power Cord
1 | 1 | TXXXV1 Food Grade Tubing (~5ft per dispenser)
1 | 3 | C024V1 Ethernet Cables (2ft each)

# B1 / B3 Kits

### Quick Start Instructions

You will need:
AC Outlet
Raspberry Pi Board
Device with Web Browser (phone, tablet, laptop, etc) Wired Networking Router (for software updates) Computer (for software updates)

### Hardware Setup:

### 1. Make sure the Raspberry Pi is securely connected to the

miniRouter Board and is supported with standoffs. Take care not to damage the header if removing the board. (gentle rocking works best)

2. Attach the provided SD Card and USB WiFi dongle to the RPI.

### 3. Connect Dispensers to the miniRouter Board using the provided

ethernet cables. Note that ethernet cables are only used for convenience and commonality, the ethernet protocol is not used.

### 4. Port numbers on the miniRouter Board should be noted when

plugging into a new Dispenser. The numbers can optionally be written down in the white box on the back of each dispenser.

### 5. Connect the Power Supply to the miniRouter Board and the Power

Supply to an AC outlet. The Raspberry Pi will begin to boot.

### 6. Once the Dispenser’s LEDs begin to fade in and out (about 1

minute), the system is ready for use. If they don’t get to this state, see the Troubleshooting section on page 8.

7. Mount the dispensers appropriatly. See dimensions on page 7.

### 8. Attach clear tubing to the dispensers using the provided

compression nuts. Make sure to budget about 5ft per pump.
Cut an angle into the bottom of the Dispenser’s input tubing to prevent it from attaching to the bottom of the bottles. See video at partyrobotics.com/docs.

# BartendroTM B1 / B3 Kits

www.partyrobotics.com | 5

### Getting Started with the User Interface

Connect to your bot:

### 1. Using a WiFi enabled device, find the “bartendro” WiFi network by

looking for it in your settings and connect to it.

### 2. Once connected (up to ~30 sec the first time) you will need to go to

a web browser, such as Chrome, and type in any web addess. You will automatically be redirected to the Bartendro user interface (UI).

### 3. The main menu may or may not have drinks populated. To tell the

bot which ingredients are present, you will need to log into the admin screen. You may do this by either searching for the hidden link at the bottom left corner of the main menu, or typing bartendro/admin in the address bar of your browser.
When prompted use the default:
Name: bartendro
Password: boozemeup

Note: Your login name and password can be modified by changing a file on the Raspberry Pi. Instructions on page 7.
Once connected to Bartendro you will have access to the following:

### Admin

Admin - Dispensers: Controls ingredient selection for each dispenser from a drop down menu. Ingredients come from the “booze” tab. Choose wisely, your drink options depend on it! Note that taking manual control comes with responsibility. The “clean” button will indescriminitely dispense all of your booze if pressed by accident and you will be a sad panda. Each dispenser can indivudially be toggled on and off by using the “turn on”/”turn off” buttons and small increments can be dispensed using the “dispense xxmL” button (helpful when priming). The “liquid levels” button forces a check of liquid levels, but this only works if the feature is enabled. See page 7. Admin - Drinks: Displays the drink list and allows you to make your own custom recipes. Select “add booze” and pick from the list of ingredients. The minimum number of parts is 1 and parts should be whole numbers, or will otherwise be rounded. All fields are required. Make sure to press save for your drink to be stored.

Admin - Booze: Displays the ingredient options and allows you to add your own custom ingredients. Adding the type, whether alcohol, sweet, or tart will allow for customizations in the drink menu.
Admin - Liquid Out: Liquid sensing is disabled by default. Only B7 and B15 kits come with these sensors. Sensors can be soldered on if desired, and sensing enabled using the steps in page 7.

### Main Menu

Menu: This is where your drinks are available for selection. The list automatically updates depending on what is loaded in the dispensers screen. Note that the menu may appear differently depending on the number of dispensers detected.
Menu - Drink Customization: After you select your drink from the menu a second screen will display allowing you to customize your drink. You will have the option to modify size, and depending on the ingredients, strength and sweetness / tartness.

### Cleaning and Maintenance

All tubing should be cleaned regularly.

### 1. Empty what remains in the tubes by turning on the dispensers. You

may use the “turn on,” “dispense xxmL” or “clean” button to do this.

### 2. Fill a pitcher with hot soapy water and place the input tubes in it

after they’ve been drained. Place a separate container underneath the spout to collect the soapy water. Press the “clean” button on the admin > dispensers screen and this will cycle through each dispenser.

### 3. Repeat step 2 but with clean water in the pitcher. Sanitizing

solutions may also be used.

### 4. Finally, run the clean cycle again with no liquids. This will empty the

tubes of liquid and prepare it for its next use.

The inner beige dispenser tubing should be replaced after 500 hours of use and removed if storing for prolonged periods of time.

### Getting under the hood:

There are several settings that aren’t exposed through the UI yet but can be changed by modifying the config.py file on the Raspberry Pi. Things like: use of liquid level sensors, display units, default size, taster buttons, the requirement to be logged in to dispense, etc.
To modify these settings:
1. Plug an ethernet cable from the RPI into a wired networking router. We’ve dissabled the ability to do this wirelessly for security reasons.

### 2. Use a terminal window on a Mac or Linux box, or use a program like

putty.exe in Windows to SSH into the bot. You may want to log into your networking router to discover the RPI’s IP address.
Once connected,
login as: bartendro
password: hackme!
You can use vi to edit:
bartendro@bartendro ~ $ vi bartendro/ui/config.py Save the file and power cycle for changes to take effect. See partyrobotics.com/docs for more detail.

### Dispenser Mounting Interface

www.partyrobotics.com; Use 4-40 or M3 screws. All dimensions in inches.

.50 | Panel thickness should be 3/32” or less.

### Troubleshooting

Dispenser LEDs are blue and /or green after power up
This is normal, LEDs will remain in this mode until proper communication with dispensers is established (about 1 min). If not getting there, make sure SD card is properly seated Dispenser LEDs are flashing red
A current limit has been triggered on a dispenser, press the “reset” button in the admin > dispensers page to restore proper operation. Check tubes for blockage.
Air bubbles in tubes, or dripping
This is a sealing issue. Make sure tubing properly protrudes from the grey compression nuts by about 1/4”. The chopstick tool is handy for this. Make sure the compression nuts are tightened so that only one or two threads are visible.
Drinks not showing up in Main Menu
Check to make sure an ingredient is selected and saved for each dispenser and that there is a drink that uses those ingredients. Make sure liquid level sensors are disabled. See page 7.

### Still Having Issues?

Try searching the forums at partyrobotics.com/forums. Post your questions so that others may learn from your issues. If stuck, email us at: support@partyrobotics.com
More documentation at:
www.partyrobotics.com/docs

### Warranty

We’re here for you! If you have made modifications to your hardware or software and are having technical issues, we will be glad to attempt to resolve them with you. If an item was damaged in shipping, or is otherwise defective or malfunctioning, please email us right away and we will do our best to make things right on a case-by-case basis.

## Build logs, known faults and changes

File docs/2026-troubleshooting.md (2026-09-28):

## Troubleshooting Guide for Bartendro (2026)

# The code is broken!

### Forgot the password or want to set a new one?  
navigate to the `http://bartendro.local/admin/lost-passwd` webpage when connected to Bartendro Wi-Fi

### Having problems accessing `bartendro.local`?
double check you are connected to the WiFi network created by the Pi, it can be helpful to remove 'auto-connect' from your configuration for other nearby wifi networks to avoid it connecting to those.

### Getting TLS/SSL certificate or secure connection errors?
this is be design, bartendro does not have a signed SSL certificate, if you can not access the app then ensure that the URL in your browser starts with `http://` and not `https://`

### Need to edit something manually? 
All the drinks/menu/dispenser settings can be manually edited in the configuration file found within `/ui/bartendro/options.py` of your Pi.
The WiFi network, bartendro username and password and other Pi related configurations are made during the install script's operation - re-run the script to edit these

# The robot is broken!

### Do you want to put carbonated drinks in Bartendro?
Well don't. The pump system does not operate well with bubbles within the system, and the corrosive nature of some of carbonated drinks can break the delicate pumps and tubing. No coca-cola, fanta, pepsi, tonic water, or other carbonated drinks should be used with Bartendro, if you wish to have a Gin and Tonic - have the robot serve the alcoholic part and the user can add tonic to their drink manually afterwards.

### I am going to use hand-pressed juices with my cocktails!
Amazing, we do as well - hand-pressed juice is the best cocktail ingredient - but you MUST strain the juice and remove all pulp or fiber from the juice. The pumps do not like pulp and fiber going through them, to avoid damaging your pumps and robot always strain your juices and if you buy it commercially ensure juices are 'pulp-free'.

### Why can't Bartendro serve me a shaken cocktail?
Because it does not have hands, but you do. The humans are expected to shake, stir or garnish their cocktails after service by the robot - Bartendro shakes for no man.

### Does liquid keep spilling out of the tubes of Bartendro?
Since this system uses peristaltic pumps, there should always be liquid within the tubes going in and out of the pumps, this system does not like air bubbles. If these tubes are draining themselves after serving a cocktail, then there is a seal problem. remove the dispenser and the rotating mechanism.
To fix this unscrew the plastic nut that connects the clear tubing with the pump's internal tubing. Then use a chopstick or other non-sharp object to push the clear tubing through the nut, there needs to be at least a 0.5 cm excess here. Once done, screw the plastic nut back and test again, the liquid should remain in the tubing after serving.

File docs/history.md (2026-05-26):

`cat history`

circa 2000: Rob meets Pierre, they love good cocktails, prototypes were made

2009: The duo found Party Robotics LLC in California with the slogan "The future of cocktails is quality drinks poured repeatably, quickly and socially. Reduce your pour costs, and automate your mundane tasks."

2010: Pierre & Rob create the `Water (to Wine) Cooler` project together: [see video](https://www.youtube.com/watch?v=Gia1HzkdTlk)

2011: first post on Party Robotics repository in January: [see commit](https://github.com/partyrobotics/bartendro/commit/c256582fca02d3f02003087d9002b98abcbdd9c0)

2011: Prototyping of the Tequila Sunrise Bot: [see video](https://www.youtube.com/watch?v=ft8u4V5cH-U)

2012: Bartendro prototyping with machine at Barbot 2012 - [see video](https://www.youtube.com/watch?v=G-F9aETMMNA) & [this one](https://www.youtube.com/watch?v=AbdYcW7BDcE)

2013: Kickstarter campaign for Bartendro launched in March - [see video](https://www.youtube.com/watch?v=bmmMHVFlmKw) - [see campaign](https://www.kickstarter.com/projects/partyrobotics/bartendro-a-cocktail-dispensing-robot) where 486 backers pledged $197,464 to help bring this Bartendro to life. Kickstarted was fully funded in less than 14 days. May 2013 production begins and by July the first units were being shipped to the backers of the campaign, by September all units were shipped - see [Kickstarter Updates](https://www.kickstarter.com/projects/partyrobotics/bartendro-a-cocktail-dispensing-robot/posts/583886).

2014: A serious amount of tasty cocktails served
 
2021: first pre-built SD card image released under Party Robotics: [see release](https://github.com/partyrobotics/bartendro/releases/tag/v-2021-05-21)

2023: Party Robotics LLC officially closes, Rob publishes [partyrobotics.github.com](partyrobotics.github.com) and redirects partyrobotics.com to it stating "Party Robotics is dead. Bartendro lives on! Party Robotics had a good run, but now what? Well, I, the co-founder of Party Robotics still have 2 bartendros at home and have regular parties. I’ll keep working to update and even improve the bartendro software, so that our bots may live on!"

2024 - 2025: Rob hosts monthly Bartendro nights in his home in Barcelona, many a cocktails and friendships were made.

2026: Rob Kaye passes away, a Monkey and Cat inherited his Bartendro and sought to revive the code: this repo

`press articles on Bartendro`

Engadget: Bartendro cocktail mixing robot lands on Kickstarter, wields Raspberry Pi (March 5, 2013) [https://www.engadget.com/2013-03-05-bartendro-raspberry-pi-cocktail-mixing-robot-kickstarter.html](https://www.engadget.com/2013-03-05-bartendro-raspberry-pi-cocktail-mixing-robot-kickstarter.html)

BoingBoing: Kickstarter for a cocktail-dispensing robot (March 4, 2013) [https://boingboing.net/2013/03/04/kickstarter-for-a-cocktail-dis.html](https://boingboing.net/2013/03/04/kickstarter-for-a-cocktail-dis.html)

[archived] WIRED: This Open Source Robot Bartender Pours the Perfect Mix (March 5, 2013) [https://web.archive.org/web/20140106025513/http://www.wired.com/design/2013/03/bartendro-robot-bartender](https://web.archive.org/web/20140106025513/http://www.wired.com/design/2013/03/bartendro-robot-bartender)

Laughing Squid: Bartendro, A Modular & Open Source Cocktail Dispensing Robot (March 5, 2013) [https://laughingsquid.com/bartendro-a-modular-open-source-cocktail-dispensing-robot](https://laughingsquid.com/bartendro-a-modular-open-source-cocktail-dispensing-robot/)

New Atlas:  Raspberry Pi-wielding Bartendro robot mixes drinks for your guests (March 5, 2013) [https://newatlas.com/bartendro-raspberry-pi-drink-robot/26526/](https://newatlas.com/bartendro-raspberry-pi-drink-robot/26526/)

[archived] CNET: Bartendro robot mixologist crafts cocktails with Raspberry Pi (March 4, 2013) [https://web.archive.org/web/20131229135530/http://news.cnet.com/8301-17938_105-57572435-1/bartendro-robot-mixologist-crafts-cocktails-with-raspberry-pi/](https://web.archive.org/web/20131229135530/http://news.cnet.com/8301-17938_105-57572435-1/bartendro-robot-mixologist-crafts-cocktails-with-raspberry-pi/)

`videos of Bartendro`

Party Robotics: Bartendro Dispenser (Jul 3, 2013) [https://www.youtube.com/watch?v=IeZ_p7Hm1Ig](https://www.youtube.com/watch?v=IeZ_p7Hm1Ig)

Party Robotics: Getting Started with Bartendro B7 / B15 Kits  [https://www.youtube.com/watch?v=Bn99R6jwX_U](https://www.youtube.com/watch?v=Bn99R6jwX_U)

Party Robotics: Bartendro Making 3 Drinks in a Row (Mar 14, 2013) [https://www.youtube.com/watch?v=X7YEHE_NLCI](https://www.youtube.com/watch?v=X7YEHE_NLCI)

Party Robotics: Bartendro 2 - Cocktail Dispensing Machine (Mar 17, 2012) [https://www.youtube.com/watch?v=G-F9aETMMNA](https://www.youtube.com/watch?v=G-F9aETMMNA)

Seeker -  Build Your Own Robot Bartender (May 23, 2013) - [https://www.youtube.com/watch?v=degF0Rp3V3I](https://www.youtube.com/watch?v=degF0Rp3V3)

Reason TV - Finally: Robot Bartenders Who Pour Stiff Drinks! (Sep 18, 2014) [https://www.youtube.com/watch?v=fV-yoZKWrzY](https://www.youtube.com/watch?v=fV-yoZKWrzY)

What's the Big Deal? - Robot Bartenders at Maker Faire (May 21, 2013) [https://www.youtube.com/watch?v=IXXLnAzce4Y](https://www.youtube.com/watch?v=IXXLnAzce4Y)

Squigglemom and Friends - Bartendro Robotic Drink Dispenser (Jul 13, 2013) [https://www.youtube.com/watch?v=uF5QksNgXFI](https://www.youtube.com/watch?v=uF5QksNgXFI)

Acumen Solutions - Bartendro at Dreamforce 2013 (Oct 10, 2014) [https://www.youtube.com/watch?v=ftDDYmJPSYI](https://www.youtube.com/watch?v=ftDDYmJPSYI)

Note: The official Party Robotics website is no longer reachable, but an Archived version exists on The Wayback Machine.

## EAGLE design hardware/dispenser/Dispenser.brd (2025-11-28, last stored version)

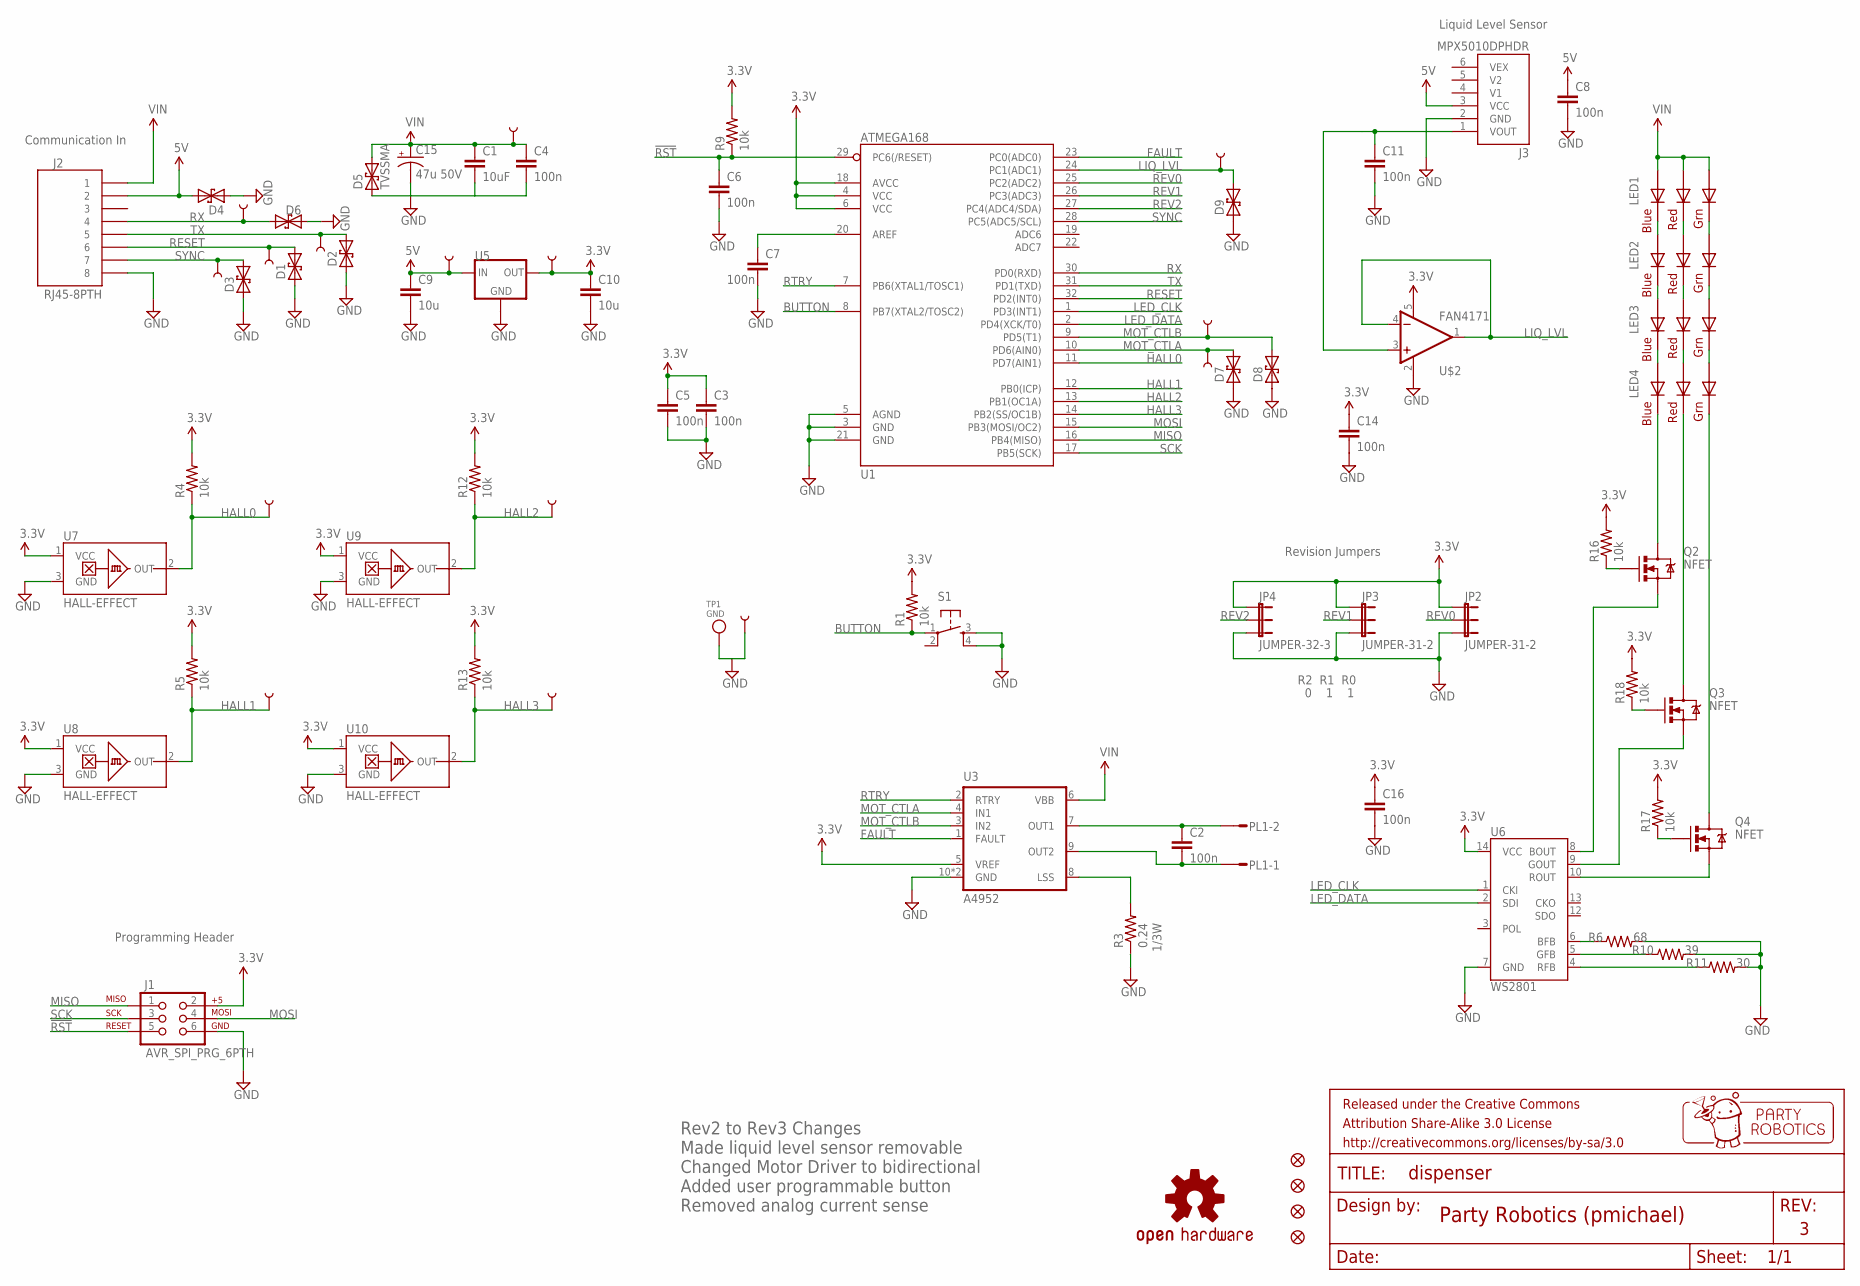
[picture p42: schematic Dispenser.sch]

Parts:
C1: 10uF; 1206
C2, C3, C4, C5, C6, C7, C8, C11, C14, C16: 100n; 0603-CAP
C9, C10: 10u; 0603-CAP
C15: 47u 50V; PANASONIC_D
D1, D2, D3, D4, D6, D7, D8, D9: TVSSOD-923; SOD-923
D5: TVSSMA; SMA-DIODE
FRAME3: FRAME-LETTER; CREATIVE_COMMONS
J1: AVR_SPI_PRG_6PTH; 2X3
J2: RJ45-8PTH; RJ45-8
J3: MPX5010DPHDR; MPX5010_HDR
JP2, JP3: JUMPER-31-2; SJ_3_PASTE1&2
JP4: JUMPER-32-3; SJ_3_PASTE2&3
JP5, JP6, JP7, JP8: FIDUCIAL1X2; FIDUCIAL-1X2
LED1, LED2, LED3, LED4: RGBLED5050
PL1: DF3-02P; DF3P-02
Q2, Q3, Q4: NFET; SOT23-3
R1, R4, R5, R9, R12, R13, R16, R17, R18: 10k; 0603-RES
R3: 0.24; 0805
R6: 68; 0603-RES
R10: 39; 0603-RES
R11: 30; 0603-RES
S1: TAC_SWITCHSMD; TACTILE_SWITCH_SMD
TP1: GND; TESTPOINT_SMT
TP2, TP3, TP4, TP5, TP6, TP13, TP14, TP15, TP16: TEST-POINT0.08; PAD_0.08
TP7, TP8, TP9, TP10, TP11, TP12: TEST-POINT3X5; PAD.03X.05
U1: ATMEGA168; TQFP32-08
U3: A4952; MSOP-10-GNDPAD
U5: VREG-5V-LDO-AP1117SOT89-3L; SOT89-3L
U6: WS2801; SOP-14
U7, U8, U9, U10: HALL-EFFECT; SOT23-3
U$1: OSHW-LOGOM; OSHW-LOGO-M
U$2: FAN4171; SOT23-5

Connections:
1/3W: R3.2, U3.8 (LSS)
3.3V: C3.1, C5.1, C10.1, C14.1, C16.1, J1.2, JP2.1, JP3.1, JP4.1, R1.2, R4.2, R5.2, R9.2, R12.2, R13.2, R16.2, R17.2, R18.2, TP16.P$1, U1.4 (VCC), U1.6 (VCC), U1.18 (AVCC), U3.5 (VREF), U5.2 (OUT), U5.2.1 (OUT), U6.14 (VCC), U7.1 (VCC), U8.1 (VCC), U9.1 (VCC), U10.1 (VCC), U$2.5 (V+)
5V: C8.1, C9.1, D4.C (2), J2.2, J3.3 (VCC), TP3.P$1, U5.3 (IN)
!RST: C6.1, J1.5, R9.1, U1.29 (PC6(/RESET))
BLUE: Q2.2 (S), U6.8 (BOUT)
BUTTON: R1.1, S1.1, U1.8 (PB7(XTAL2/TOSC2))
FAULT: U1.23 (PC0(ADC0)), U3.1 (FAULT)
GND: C1.2, C3.2, C4.2, C5.2, C6.2, C7.2, C8.2, C9.2, C10.2, C11.2, C14.2, C15.-, C16.2, D1.A (1), D2.A (1), D3.A (1), D4.A (1), D5.A (1), D6.A (1), D7.A (1), D8.A (1), D9.A (1), J1.6, J2.8, J3.2 (GND), JP2.3, JP3.3, JP4.3, R3.1, R6.2, R10.2, R11.2, S1.3, S1.4, TP1.P$1, TP2.P$1, U1.3 (GND), U1.5 (AGND), U1.21 (GND), U3.10 (GND), U3.GND, U5.1 (GND), U6.7 (GND), U7.3 (GND), U8.3 (GND), U9.3 (GND), U10.3 (GND), U$2.2 (V-)
GREEN: Q3.2 (S), U6.9 (GOUT)
HALL0: R4.1, TP10.P$1, U1.11 (PD7(AIN1)), U7.2 (OUT)
HALL1: R5.1, TP11.P$1, U1.12 (PB0(ICP)), U8.2 (OUT)
HALL2: R12.1, TP9.P$1, U1.13 (PB1(OC1A)), U9.2 (OUT)
HALL3: R13.1, TP12.P$1, U1.14 (PB2(SS/OC1B)), U10.2 (OUT)
LED_CLK: U1.1 (PD3(INT1)), U6.1 (CKI)
LED_DATA: U1.2 (PD4(XCK/T0)), U6.2 (SDI)
LIQ_LVL: D9.C (2), TP14.P$1, U1.24 (PC1(ADC1)), U$2.1 (OUT), U$2.4 (-IN)
MISO: J1.1, U1.16 (PB4(MISO))
MOSI: J1.4, U1.15 (PB3(MOSI/OC2))
MOT_CTLA: D7.C (2), TP8.P$1, U1.10 (PD6(AIN0)), U3.4 (IN1)
MOT_CTLB: D8.C (2), TP7.P$1, U1.9 (PD5(T1)), U3.3 (IN2)
unnamed: C7.1, U1.20 (AREF)
unnamed: Q3.1 (G), R18.1
unnamed: Q4.1 (G), R17.1
unnamed: Q2.1 (G), R16.1
unnamed: R6.1, U6.6 (BFB)
unnamed: R10.1, U6.5 (GFB)
unnamed: R11.1, U6.4 (RFB)
unnamed: C2.1, PL1.2, U3.7 (OUT1)
unnamed: C2.2, PL1.1, U3.9 (OUT2)
unnamed: LED4.6 (BLUE_C), Q2.3 (D)
unnamed: LED4.5 (RED_C), Q3.3 (D)
unnamed: LED4.4 (GREEN_C), Q4.3 (D)
unnamed: Q4.2 (S), U6.10 (ROUT)
unnamed: C11.1, J3.1 (VOUT), U$2.3 (+IN)
unnamed: LED3.6 (BLUE_C), LED4.1 (BLUE_A)
unnamed: LED3.5 (RED_C), LED4.2 (RED_A)
unnamed: LED3.4 (GREEN_C), LED4.3 (GREEN_A)
unnamed: LED2.4 (GREEN_C), LED3.3 (GREEN_A)
unnamed: LED2.5 (RED_C), LED3.2 (RED_A)
unnamed: LED2.6 (BLUE_C), LED3.1 (BLUE_A)
unnamed: LED1.4 (GREEN_C), LED2.3 (GREEN_A)
unnamed: LED1.5 (RED_C), LED2.2 (RED_A)
unnamed: LED1.6 (BLUE_C), LED2.1 (BLUE_A)
RESET: D1.C (2), J2.6, TP13.P$1, U1.32 (PD2(INT0))
REV0: JP2.2, U1.25 (PC2(ADC2))
REV1: JP3.2, U1.26 (PC3(ADC3))
REV2: JP4.2, U1.27 (PC4(ADC4/SDA))
RTRY: U1.7 (PB6(XTAL1/TOSC1)), U3.2 (RTRY)
RX: D6.C (2), J2.4, TP4.P$1, U1.30 (PD0(RXD))
SCK: J1.3, U1.17 (PB5(SCK))
SYNC: D3.C (2), J2.7, TP15.P$1, U1.28 (PC5(ADC5/SCL))
TX: D2.C (2), J2.5, TP5.P$1, U1.31 (PD1(TXD))
VIN: C1.1, C4.1, C15.+, D5.C (2), J2.1, LED1.1 (BLUE_A), LED1.2 (RED_A), LED1.3 (GREEN_A), TP6.P$1, U3.6 (VBB)

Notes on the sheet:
Programming Header
Liquid Level Sensor
Party Robotics (pmichael)
Communication In
Revision Jumpers
R2 R1 R0
0 1 1
Rev2 to Rev3 Changes Made liquid level sensor removable Changed Motor Driver to bidirectional Added user programmable button Removed analog current sense

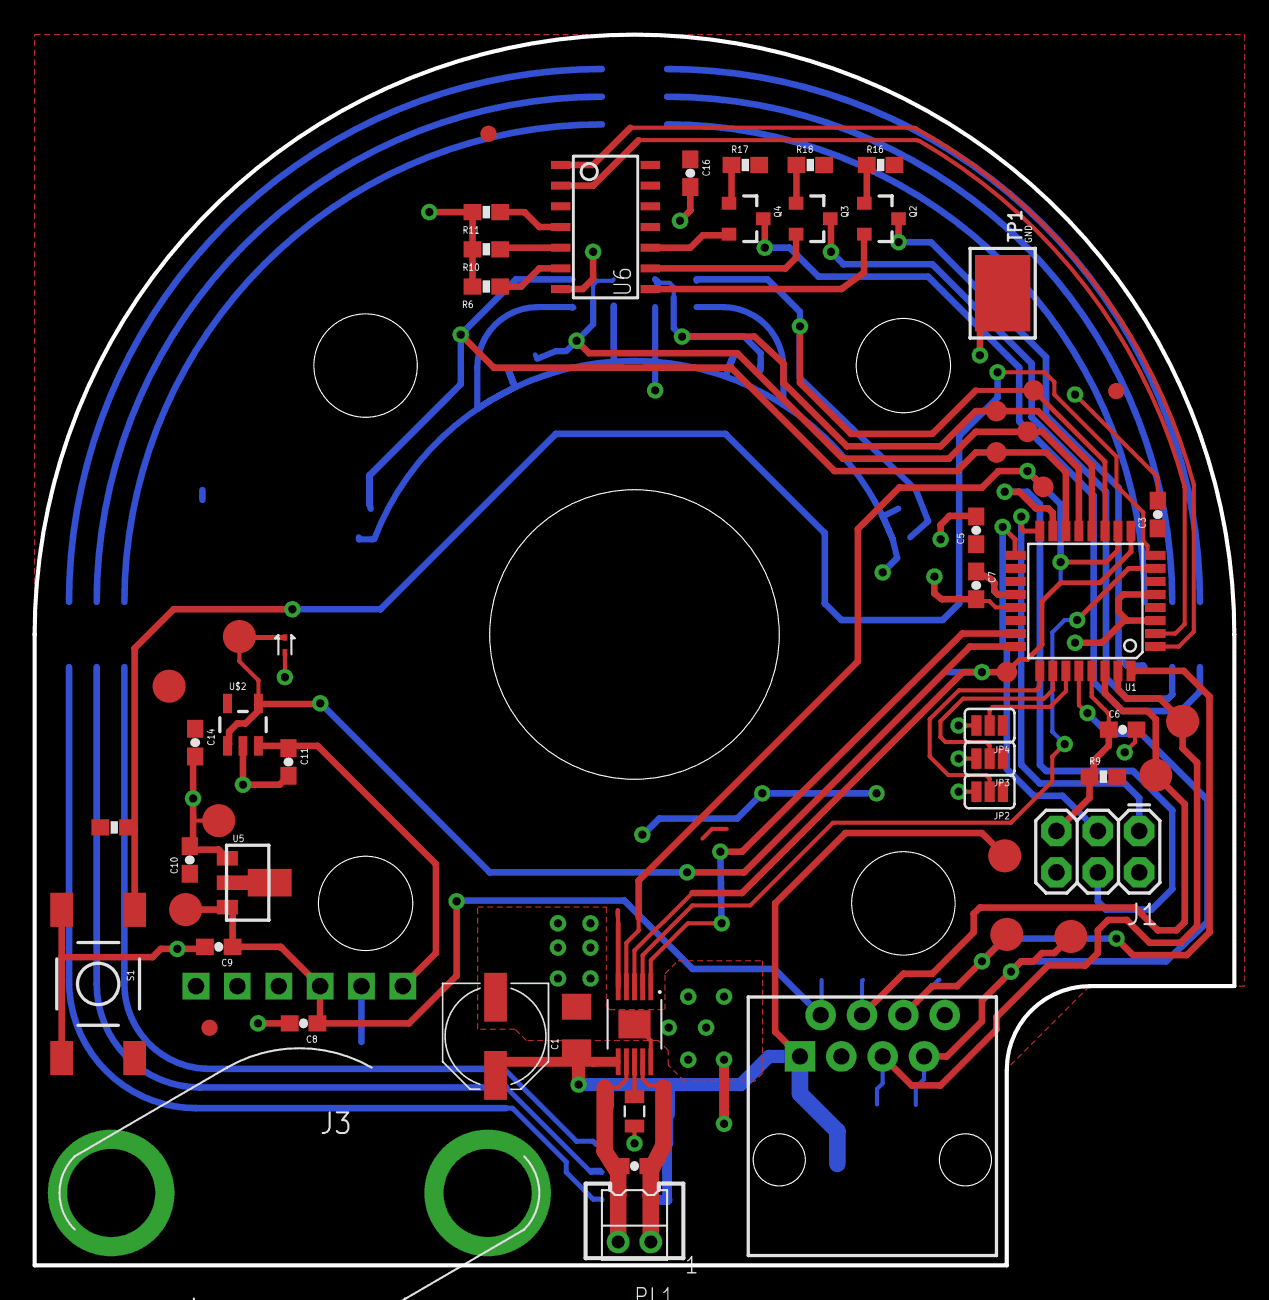
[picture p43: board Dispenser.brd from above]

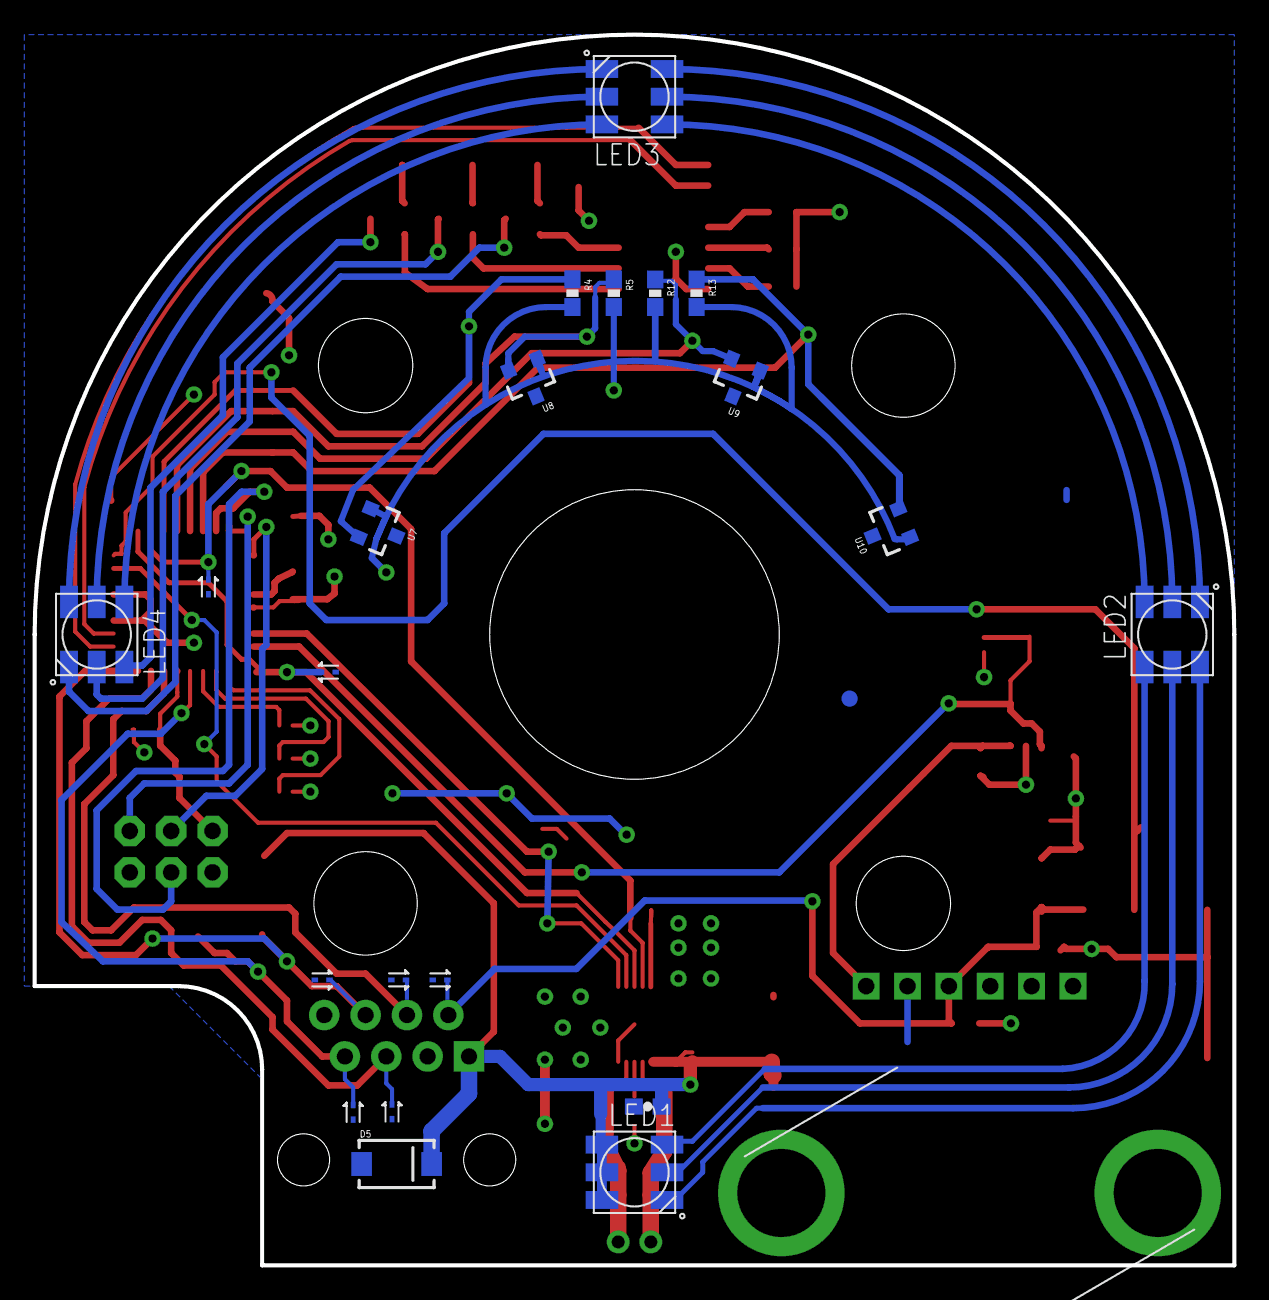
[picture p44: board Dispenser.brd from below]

Board: 2 copper layers, 73.7 x 75.6 mm, 82 parts (22 on the bottom side), 53 nets.

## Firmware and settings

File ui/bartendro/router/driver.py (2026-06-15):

import sys
import os
import collections
import logging
from subprocess import call
from time import sleep, localtime, time
import serial
from struct import pack, unpack
from . import pack7
from . import dispenser_select
from bartendro.error import SerialIOError
import random

DISPENSER_DEFAULT_VERSION = 2
DISPENSER_DEFAULT_VERSION_SOFTWARE_ONLY = 3

BAUD_RATE = 9600
DEFAULT_TIMEOUT = 2  # in seconds
DISCOVERY_TIMEOUT = 0.05
DISCOVERY_SELECT_SETTLE = 0.05
DISCOVERY_ZERO_RETRIES = 3

MAX_DISPENSERS = 15
SHOT_TICKS = 20

RAW_PACKET_SIZE = 10
PACKET_SIZE = 8

PACKET_ACK_OK = b"\x00"
PACKET_CRC_FAIL = b"\x01"
PACKET_ACK_TIMEOUT = b"\x02"
PACKET_ACK_INVALID = b"\x03"
PACKET_ACK_INVALID_HEADER = b"\x04"
PACKET_ACK_HEADER_IN_PACKET = b"\x05"
PACKET_ACK_CRC_FAIL = b"\x06"

PACKET_PING = 3
PACKET_SET_MOTOR_SPEED = 4
PACKET_TICK_DISPENSE = 5
PACKET_TIME_DISPENSE = 6
PACKET_LED_OFF = 7
PACKET_LED_IDLE = 8
PACKET_LED_DISPENSE = 9
PACKET_LED_DRINK_DONE = 10
PACKET_IS_DISPENSING = 11
PACKET_LIQUID_LEVEL = 12
PACKET_UPDATE_LIQUID_LEVEL = 13
PACKET_ID_CONFLICT = 14
PACKET_LED_CLEAN = 15
PACKET_SET_CS_THRESHOLD = 16
PACKET_SAVED_TICK_COUNT = 17
PACKET_RESET_SAVED_TICK_COUNT = 18
PACKET_GET_LIQUID_THRESHOLDS = 19
PACKET_SET_LIQUID_THRESHOLDS = 20
PACKET_FLUSH_SAVED_TICK_COUNT = 21
PACKET_TICK_SPEED_DISPENSE = 22
PACKET_PATTERN_DEFINE = 23
PACKET_PATTERN_ADD_SEGMENT = 24
PACKET_PATTERN_FINISH = 25
PACKET_SET_MOTOR_DIRECTION = 26
PACKET_GET_VERSION = 27
PACKET_COMM_TEST = 0xFE

DEST_BROADCAST = 0xFF

MOTOR_DIRECTION_FORWARD = 1
MOTOR_DIRECTION_BACKWARD = 0

LED_PATTERN_IDLE = 0
LED_PATTERN_DISPENSE = 1
LED_PATTERN_DRINK_DONE = 2
LED_PATTERN_CLEAN = 3
LED_PATTERN_CURRENT_SENSE = 4

MOTOR_DIRECTION_FORWARD = 1
MOTOR_DIRECTION_BACKWARD = 0

log = logging.getLogger('bartendro')


def crc16_update(crc, a):
    crc ^= a
    for i in range(0, 8):
        if crc & 1:
            crc = (crc >> 1) ^ 0xA001
        else:
            crc = (crc >> 1)
    return crc


class RouterDriver(object):
    '''This object interacts with the bartendro router controller.'''

    def __init__(self, device, software_only):
        self.device = device
        self.ser = None
        self.msg = ""
        self.ret = 0
        self.software_only = software_only
        self.dispenser_select = None
        self.dispenser_version = DISPENSER_DEFAULT_VERSION
        self.startup_log = ""
        self.debug_levels = [200, 180, 120]

        # dispenser_ids are the ids the dispensers have been assigned. These are logical ids
        # used for dispenser communication.
        self.dispenser_ids = [-1 for i in range(MAX_DISPENSERS)]

        # dispenser_ports are the ports the dispensers have been plugged into.
        self.dispenser_ports = [255 for i in range(MAX_DISPENSERS)]

        if software_only:
            self.num_dispensers = 8
        else:
            self.num_dispensers = 0

    def get_startup_log(self):
        return self.startup_log

    def get_dispenser_version(self):
        return self.dispenser_version

    def reset(self):
        """Reset the hardware. Do this if there is shit going wrong. All motors will be stopped
           and reset."""
        if self.software_only: return

        self.close()
        self.open()

    def count(self):
        return self.num_dispensers

    def set_timeout(self, timeout):
        self.ser.timeout = timeout

    def open(self):
        '''Open the serial connection to the router'''

        if self.software_only: return

        self._clear_startup_log()

        try:
            log.info("Opening %s" % self.device)
            self.ser = serial.Serial(self.device,
                                     BAUD_RATE,
                                     bytesize=serial.EIGHTBITS,
                                     parity=serial.PARITY_NONE,
                                     stopbits=serial.STOPBITS_ONE,
                                     timeout=.01)
        except serial.serialutil.SerialException as e:
            raise SerialIOError(e)

        log.info("Done.\n")

        from . import status_led
        self.status = status_led.StatusLED(self.software_only)
        self.status.set_color(0, 0, 1)

        self.dispenser_select = dispenser_select.DispenserSelect(MAX_DISPENSERS, self.software_only)
        self.dispenser_select.open()
        self.dispenser_select.reset()

        # This primes the communication line.
        self.ser.write(bytearray((170, 170, 170)))
        sleep(.001)

        log.info("Discovering dispensers")
        self.num_dispensers = 0
        self.set_timeout(DISCOVERY_TIMEOUT)
        for port in range(MAX_DISPENSERS):
            self._log_startup("port %d:" % port)
            self.dispenser_select.select(port)
            sleep(DISCOVERY_SELECT_SETTLE)
            zero_reads = 0
            while True:
                self.ser.flushInput()
                self.ser.write(bytearray((63, 63, 63)))
                data = self.ser.read(3)
                ll = ""
                for ch in data:
                    ll += "%02X " % ch
                if len(data) == 3:
                    if data[0] != data[1] or data[0] != data[2]:
                        self._log_startup("  %s -- inconsistent" % ll)
                        continue

                    if data[0] == 0:
                        zero_reads += 1
                        if zero_reads < DISCOVERY_ZERO_RETRIES:
                            self._log_startup("  %s -- dispenser id 0, retrying." % ll)
                            sleep(DISCOVERY_SELECT_SETTLE)
                            continue

                        self._log_startup("  %s -- ignoring dispenser id 0." % ll)
                        break

                    id = data[0]
                    self.dispenser_ids[self.num_dispensers] = id
                    self.dispenser_ports[self.num_dispensers] = port
                    self.num_dispensers += 1
                    self._log_startup("  %s -- Found dispenser with pump id %02X, index %d" % (ll, id, self.num_dispensers))
                    break
                elif len(data) > 1:
                    self._log_startup("  %s -- Did not receive 3 characters back. Trying again." % ll)
                    sleep(.5)
                else:
                    break

        self._select(0)
        self.set_timeout(DEFAULT_TIMEOUT)
        self.ser.write(bytearray((255,)))
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

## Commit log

2025-11-28 Remove annoying bottle size drop downs and fix changing dispense button
    [Dispenser.brd, Dispenser.sch]
2026-05-13 Renamed updated-sd-cards.txt to history.md
    Created a file to track the history of the projet and its various iterations
2026-05-13 Uploading Dispenser pin-out diagram
    extracted from archived version of partyrobotics.com
2026-05-27 ROADMAP update
    Items were moved to strech goals, ticked some checkboxes for things we completed, and reordered things according to current prorities in the project
2026-06-15 Fix serial port activation
    "do_serial 2" disables the login shell on serial and enables the serial hardware. This is available on older Raspberry Pi OS releases while do_serial_hw/do_serial_cons are not consistently available.
2026-06-15 Raspberry hardware setup: prefer non-interactive mode
    Fallback to interactive mode
2026-06-15 Improve dispenser discovery routine
    Larger timeout, and retries, trying to solve dispensers communication issues
    [driver.py]
2026-11-05 Log formatter: use milliseconds, remove timezone
    timezone is only marginally useful, but having better granularity with milliseconds is very useful
2026-11-05 FSM: Print state description, not just state code
    state 0 or state 1 tells me nothing, but "OUT", "LOW" or "OK" makes the logs a lot easier to read.
2026-11-10 Don't capture DNS resolution on ethernet port
    previously, dnsmasq was set up to loopback all dns resolution, for the local wifi access point. However, we want to be able to plug the raspberry to ethernet and have internet access to do things.
2026-11-10 Re-enable dispenser reset code
    not sure why that was commented out 3 years ago, but we should be able to send a command to the router board to reset the dispensers. Currently the command does nothing.

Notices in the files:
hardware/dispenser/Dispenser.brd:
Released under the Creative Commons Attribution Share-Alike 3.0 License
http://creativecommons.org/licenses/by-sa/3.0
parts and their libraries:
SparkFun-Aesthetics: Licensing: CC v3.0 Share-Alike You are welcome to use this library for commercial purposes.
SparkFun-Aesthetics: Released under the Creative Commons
